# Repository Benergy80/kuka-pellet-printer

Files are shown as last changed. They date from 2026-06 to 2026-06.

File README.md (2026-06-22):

# KUKA Pellet 3D Printer — Conversion Plan

Planning materials for converting a KUKA KR 150 / 180 robot (KR C2 controller)
into a large-format pellet (granule) 3D printer.

## Contents

- **`index.html`** — Interactive implementation plan. Open in any web browser.
  Covers system architecture, the build platform (rigid table, heated bed,
  enclosure/safety), electrical & DeviceNet I/O wiring, the software pipeline,
  calibration, a commissioning roadmap, and an interactive, filterable Bill of
  Materials with live cost totals and charts.
- **`KUKA_Pellet_3D_Printer_Implementation.pptx`** — The same plan as a
  presentation deck with diagrams and charts.
- **`build.js`** — Node.js script (PptxGenJS) that generates the deck.

## Regenerating the deck

```bash
npm install pptxgenjs react-icons react react-dom sharp
node build.js
```

## ⚠️ Safety

This is planning material only. The 480 V three-phase power connection and the
robot safety-circuit wiring (fence interlocks, E-stops) **must** be performed
and validated by a licensed electrician and a qualified machine-safety
integrator. Do not run the robot unattended until safety, thermal, and e-stop
behavior are all proven.

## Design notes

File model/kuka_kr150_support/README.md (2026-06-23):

# KUKA KR 150 robot model (`kr150_2`)

Vendored from **ROS-Industrial** [`kuka_experimental`](https://github.com/ros-industrial/kuka_experimental) → `kuka_kr150_support` (branch `melodic-devel`).

- **License:** Apache-2.0 (ROS-Industrial). Original copyright retained.
- **Contents:** URDF/xacro + meshes — `visual/*.dae` (textured/colored) and `collision/*.stl` (decimated) for the **`kr150_2`** arm, the older 2-series arm that is the closest match to a **KR C2-era** machine.

## Where it's used
- **`/twin.html`** — interactive browser 3D twin. Uses the **collision STLs** (small, fast, no Collada up-axis quirks) assembled with the kinematics below.
- **RViz / MoveIt / Gazebo** — drop the package into a catkin/colcon workspace and use the xacro directly.
- **RoboDK / CAD** — import the **visual DAE** meshes for a higher-fidelity render.

## Kinematic chain (from the package URDF — units: m, °)

| Joint | Origin (xyz) | Axis | Limits |
|---|---|---|---|
| A1 | 0, 0, 0.75 | (0, 0, −1) | −185 … 185 |
| A2 | 0.35, 0, 0 | (0, 1, 0)  | −146 … 0 |
| A3 | 1.25, 0, 0 | (0, 1, 0)  | −119 … 155 |
| A4 | 0, 0, −0.055  | (−1, 0, 0) | −350 … 350 |
| A5 | 1.1, 0, 0 | (0, 1, 0)  | −125 … 125 |
| A6 | 0.23, 0, 0 | (−1, 0, 0) | −350 … 350 |
| flange → tool0 | fixed | rpy (0, 90°, 0) | — |

Note: the `kr150_2` arm geometry approximates the KR C2-era robot. For a different reach/payload variant (e.g. KR 150 L, KR 210), confirm against the robot's rating plate and swap the matching ROS-Industrial support package.

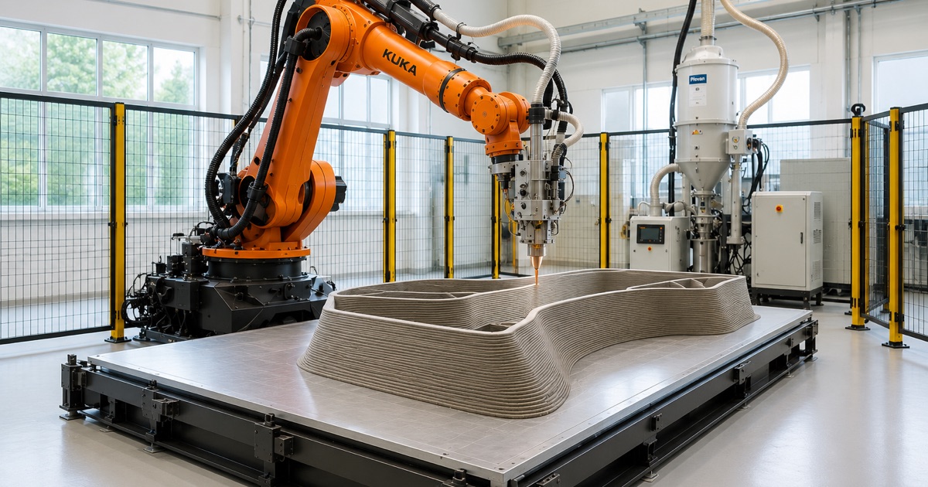
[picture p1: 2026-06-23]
images/og-cover.jpg

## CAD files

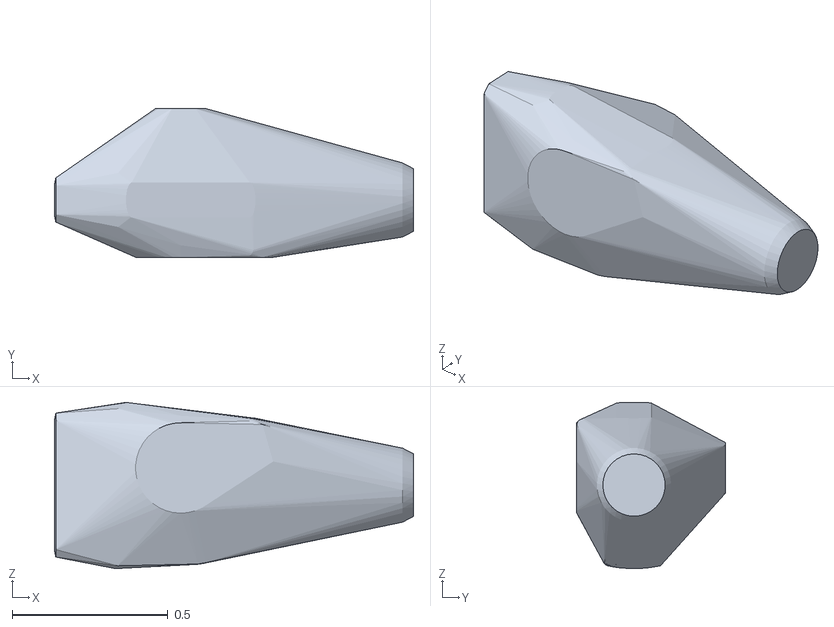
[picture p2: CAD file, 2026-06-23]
model/kuka_kr150_support/meshes/kr150_2/collision/link_3.stl
1.15 x 0.477 x 0.533

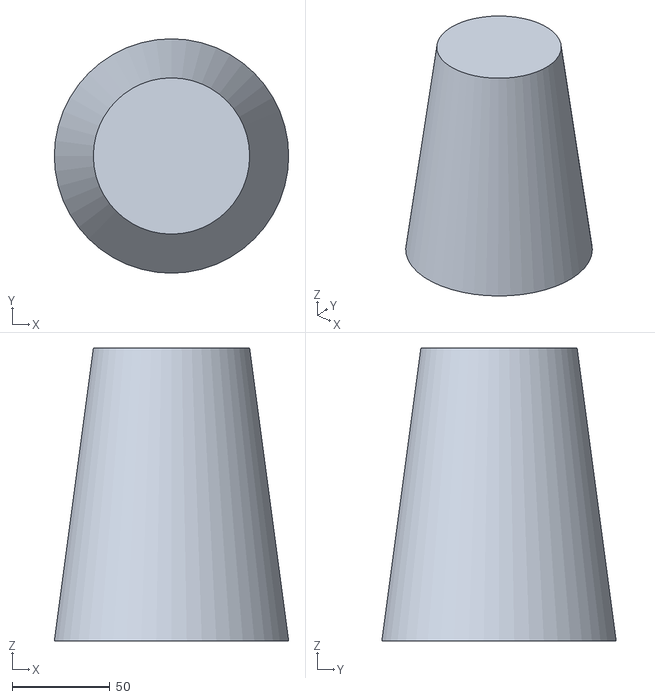
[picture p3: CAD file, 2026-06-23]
samples/vase.stl
120.0 x 120.0 x 150.0

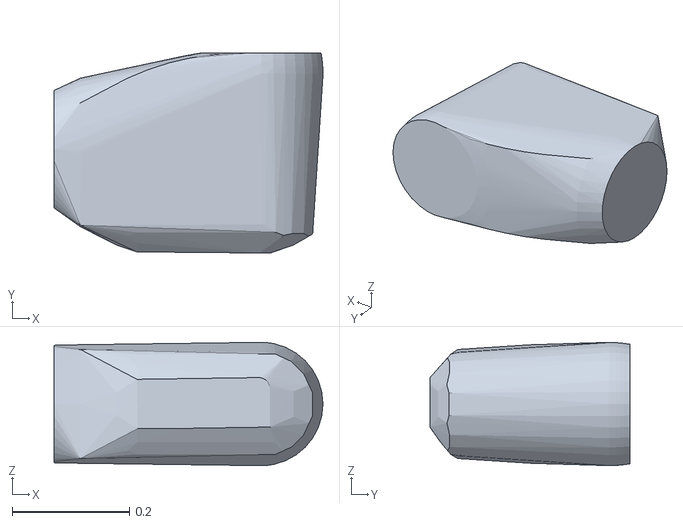
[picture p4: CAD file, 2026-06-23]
model/kuka_kr150_support/meshes/kr150_2/collision/link_4.stl
0.458 x 0.341 x 0.21

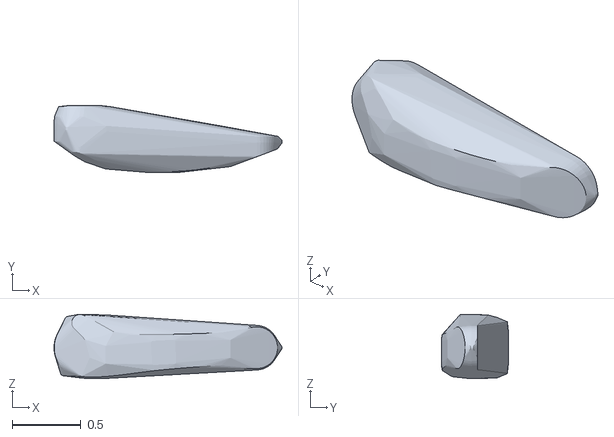
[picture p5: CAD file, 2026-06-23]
model/kuka_kr150_support/meshes/kr150_2/collision/link_2.stl
1.66 x 0.492 x 0.47

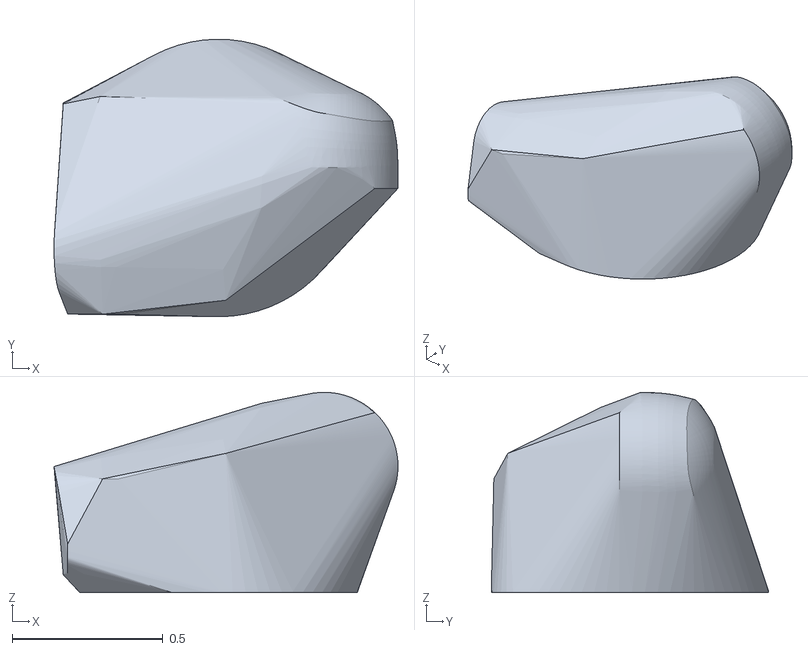
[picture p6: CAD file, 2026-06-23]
model/kuka_kr150_support/meshes/kr150_2/collision/link_1.stl
1.14 x 0.92 x 0.664

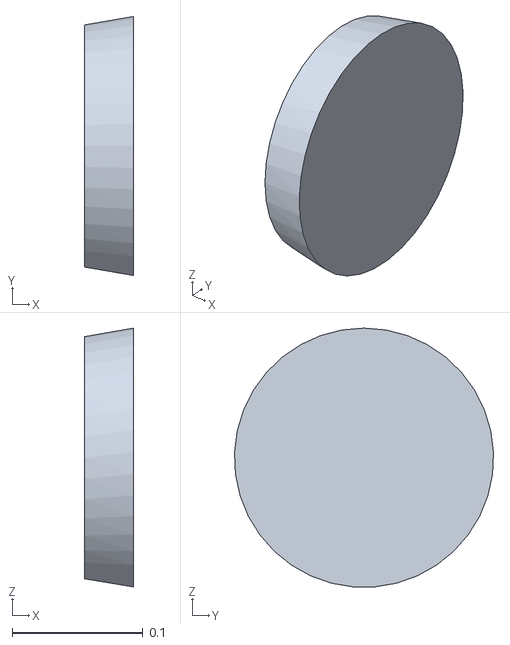
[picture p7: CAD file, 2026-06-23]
model/kuka_kr150_support/meshes/kr150_2/collision/link_6.stl
0.0375 x 0.198 x 0.198

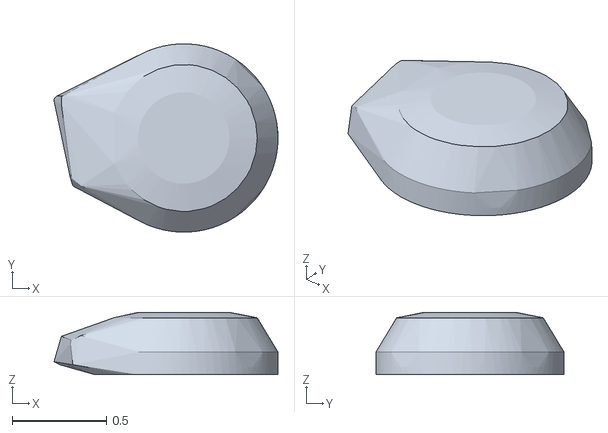
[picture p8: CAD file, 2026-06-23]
model/kuka_kr150_support/meshes/kr150_2/collision/base_link.stl
1.19 x 1 x 0.331

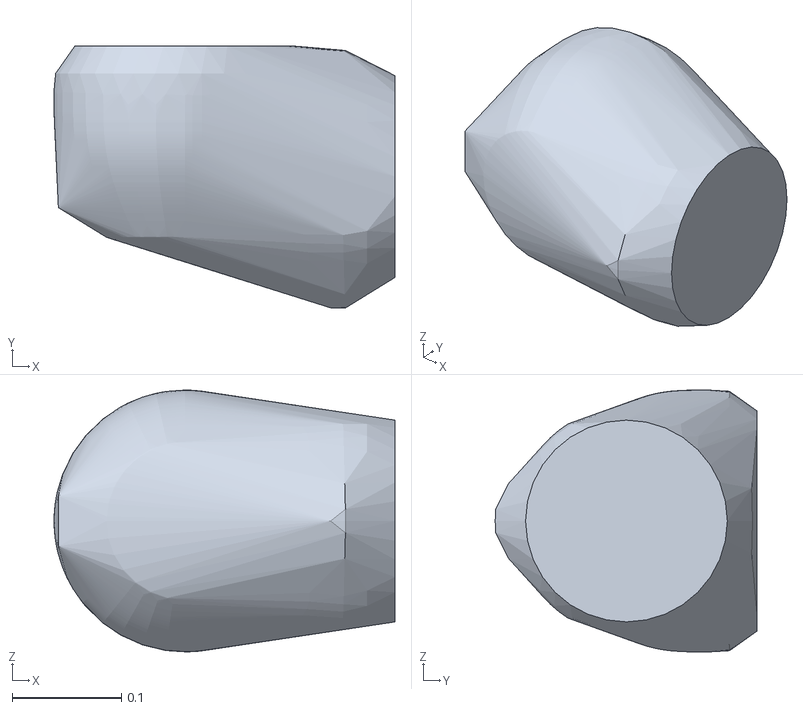
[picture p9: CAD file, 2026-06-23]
model/kuka_kr150_support/meshes/kr150_2/collision/link_5.stl
0.313 x 0.24 x 0.24

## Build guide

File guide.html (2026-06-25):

KUKA Pellet PrinterLFAM Build Manual 3D Twin Overview Download PDF

Engineering Build Manual · LFAM

# Converting a KUKA KR 150/180 into a Pellet 3D Printer

A high-fidelity, primary-source-cited manual — mechanical, electrical & DeviceNet I/O, safety, software & simulation, calibration, and commissioning for a large-format additive manufacturing cell.

KR 150 / 180 · ZH 150/180 I KR C2 · KSS 5.x · KRL DeviceNet I/O Pellet Extrusion (FGF)

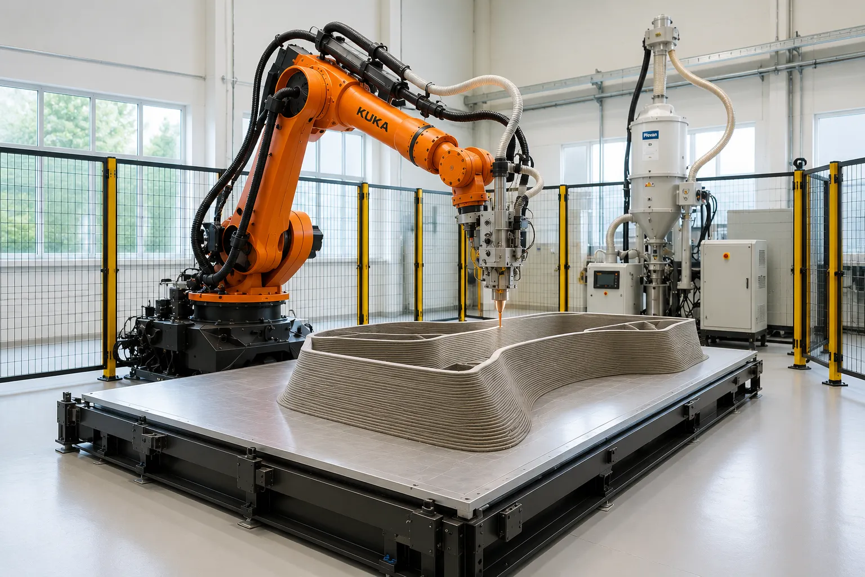
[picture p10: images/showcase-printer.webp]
KUKA robot arm printing a large part from plastic pellets


Revision 1.0 · June 2026 · For planning use — power and safety-circuit work must be performed by qualified, licensed professionals.

Read first — scope & safetyThis is a planning and engineering reference, not a substitute for professional judgment. A KUKA KR 150/180 is a ~1,250 kg machine that moves a multi-kilogram tool at up to ~2 m/s and carries a 350 °C hot end. The 480/400 V power feed and the safety circuit must be executed and validated by a licensed electrician and a qualified machine-safety integrator. Every numbered pin, jumper, and rating below must be confirmed against your specific cabinet's wiring diagram and rating plate before you wire anything. Where a value could not be confirmed against a primary source, it is flagged.

## 01System & specifications

A 6-axis KUKA arm carries a pellet (granule) extruder and prints large parts directly from thermoplastic pellets — no filament. The motion system and the feedstock chain are in hand; the work is integration, a build platform, control I/O, software, and safety.

150–180 kg

Rated payload — carries any pellet head with margin

3100 mm

Max reach (base 1100 mm arm) — defines the build envelope

±0.15 mm

Pose repeatability (ISO 9283), KR 150/180

~1245–1267 kg

Robot mass — drives the foundation design

### Verified robot data (KR 150 / 180 / 210 family)

The KR 150, 180 and 210 share one mechanical platform (1100 mm base arm); they differ mainly in payload and axis speed. "ZH 150/180 I" denotes the KUKA Zentralhand (in-line wrist) rated 150/180 kg — confirming the donor wrist module. Source: KUKA (V)KR 150,180,210 Technical Data.

Parameter | KR 150 | KR 180 | KR 210
Rated payload | 150 kg | 180 kg | 210 kg
Suppl. load (arm / link arm / column) | 50 / 100 / 300 kg | | 50 / 100 / 300 kg
Max reach (base arm) | 3100 mm | | 3100 mm
Repeatability (ISO 9283) | ±0.15 mm | ±0.15 mm | ±0.2 mm
Robot mass | 1245 kg | 1267 kg | 1267 kg
Installed motor capacity | 21.6 kW | 22.8 kW | 23.4 kW
Protection / mounting | IP 65 (wrist); floor or ceiling, ≤5° incline; +10…+55 °C ambient

#### Axis motion ranges (software-limited)

Axis | Range | Speed @ KR 150 | Speed @ KR 180
A1 | ±185° | 110 °/s | 95 °/s
A2 | +90° … −61° | 110 °/s | 95 °/s
A3 | +65° … −209° | 100 °/s | 90 °/s
A4 | ±350° | 170 °/s | 162 °/s
A5 | ±125° | 170 °/s | 164 °/s
A6 | ±350° | 238 °/s | 229 °/s

Verify on the nameplateIf the donor is actually a KR 210 or an "L" long-arm variant, payload and reach change (L-arms reach 3300–3500 mm at reduced payload). Read the model and machine-data number off the robot's rating plate and cross-check in KUKA Xpert.

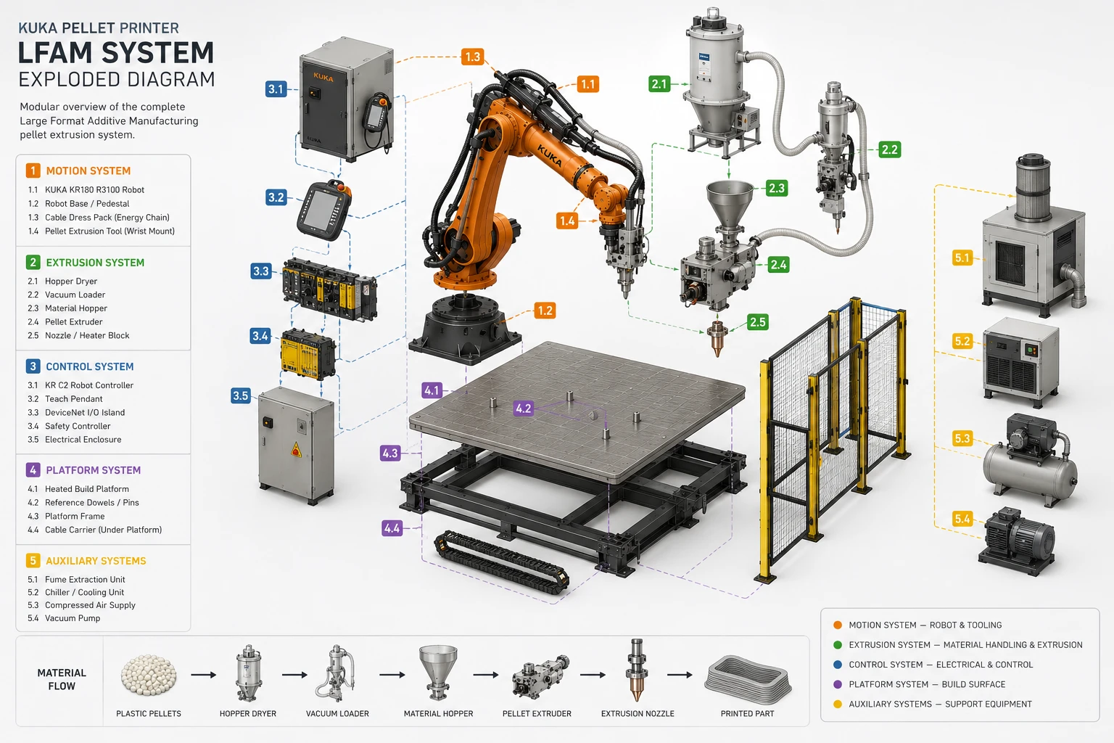
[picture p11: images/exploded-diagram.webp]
Exploded diagram of the LFAM system grouped into motion, extrusion, control, platform, and auxiliary subsystems


System map. Five subsystems — motion, extrusion, control, platform, auxiliary — and how they connect.

## 02Mechanical & tool flange

Only the extruder head rides on the arm; the control box stays off-arm to keep the moving mass and inertia low. The head bolts to the wrist flange through a machined adapter.

### Mounting flange — DIN/ISO 9409-1-A160

The in-line wrist flange is DIN/ISO 9409-1-A160 (Type A, 160 mm bolt-circle). Tooling fastens with M10, grade 10.9 screws; thread engagement 12–14 mm; a locating bushing/dowel fixes orientation. Design the adapter plate to register on the center pilot and one dowel, and follow KUKA's rule that screw grip length ≥ 1.5 × nominal diameter (≥ 15 mm for M10).

Flange feature | Value
Standard | DIN/ISO 9409-1-A160 (160 mm BCD)
Fastening screws | M10 × grade 10.9
Thread engagement | min 12 mm / max 14 mm
Locating | center pilot register + locating bushing (dowel)

Confirm before machiningThe exact bolt count and locating-pin coordinates are dimensioned in KUKA Fig. 16 / the STEP model — pull the CAD from KUKA Xpert (or the ROS-Industrial mesh, §10) and dimension the adapter from it rather than assuming.

### Payload, centre of gravity & inertia

The pellet head (~6 kg) plus adapter, hose drag and any on-arm feed tube must stay within the wrist's load model. Nominal design point: load CG at Lz ≈ 240 mm from the flange face, Lxy ≈ 270 mm from the A6 axis; permissible mass moment of inertia ≤ 75 kg·m² (KR 150). Compute the real values in KUKA.Load and enter them in the controller — an out-of-spec CG/inertia degrades path accuracy and can trip drive faults.

#### Model the head + adapter

- Get mass, CG and inertia of the extruder head, adapter plate, mounted hose section and any cable carrier. Keep the control box and reservoir off the arm.

#### Machine the adapter to A160

- 160 mm BCD, center pilot, dowel bore; material thick enough to be stiff under bead-reaction and decel loads. Route the melt/feed lines so they don't snag through the A4–A6 range.

#### Enter load data

- Run KUKA.Load; enter mass/CG/inertia as the active TOOL load. Verify the arm accepts full-speed moves across the print envelope without overload warnings.

## 03Foundation & build table

The robot base and the print table must not move relative to each other — they share one rigid datum, ideally one concrete slab. If the table shifts, the calibrated BASE frame is lost and Z accuracy goes with it.

### Foundation

Requirement | Value (representative KUKA spec)
Concrete thickness | ≥ 200 mm (heavier cells ~400 mm)
Concrete grade | C20/25 (EN 206-1)
Anchors | chemical (resin-bonded) anchors, Dynamic Set
Base loads (design) | Fv 24 kN · Fh 18 kN · Mk 49 kN·m · Mr 38 kN·m

VerifyUse the KR 150/180 model's own KUKA assembly-instruction foundation drawing for footprint, bolt circle and dynamic forces before pouring.

### Build table

Build a stiff steel weldment with a thick flat top plate. Use cast aluminium tooling plate (MIC-6 or ATP-5/Alca-5) for the build surface — it is internally stress-relieved and holds flatness, where rolled 6061 will not.

Plate | Flatness (as supplied) | At thickness
MIC-6 (Arconic) | 0.005" (0.13 mm) | ≥ 19 mm (¾")
ATP-5 / Alca-5 | 0.005" (0.13 mm) | ≥ 16 mm (⅝")

- Top plate ≥ 15–25 mm on a welded steel sub-frame; flycut/grind after mounting and verify with a straightedge.
- Anchor to the same slab as the robot; level on adjustable feet.
- Machine 2 dowel bores + a datum edge so the BASE frame can be re-taught identically after a bed/plate swap.
- Mount the heated bed on a thermal break so the frame doesn't sink the heat.

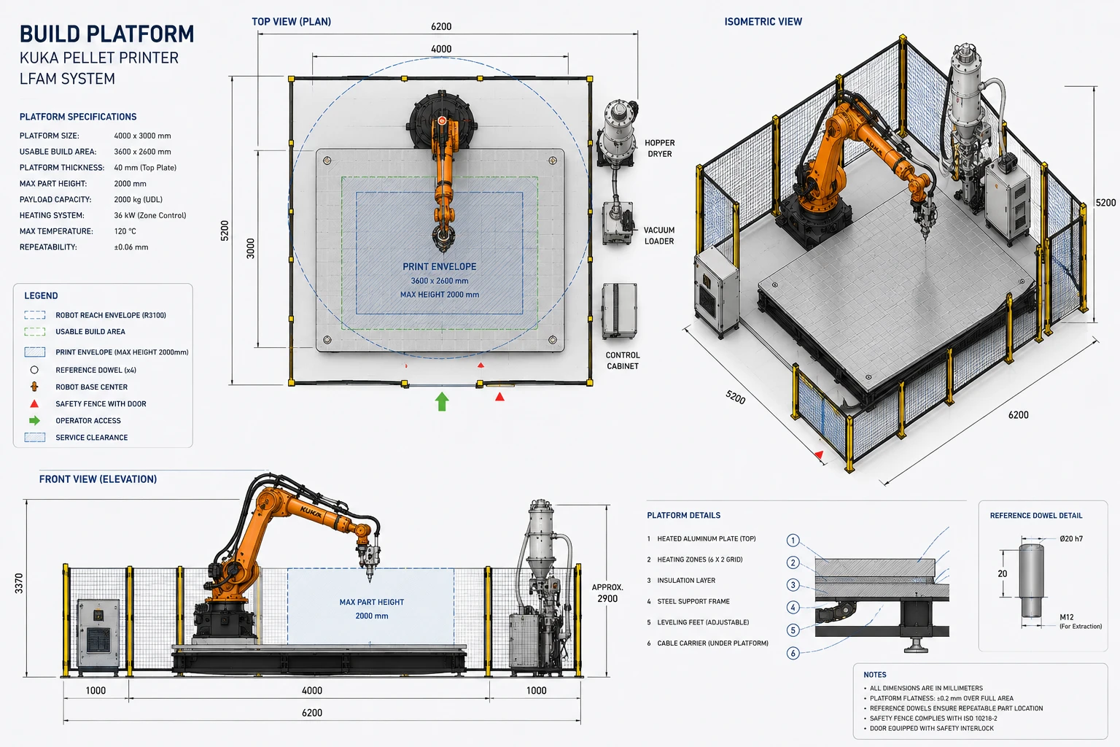
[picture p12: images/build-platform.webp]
Build platform engineering drawing: plan, isometric and front elevation with print envelope, fencing and reference-dowel detail


Build platform — general arrangement. Print envelope inside the reach circle, reference dowels, fencing, and heated-plate stack-up.

## 04Heated bed & thermal

Big beads shrink as they cool and try to peel off the plate. A heated bed plus a warm chamber keep the temperature gradient low — controlling warp and building interlayer bond strength.

### Heater sizing & control loop

Spec a silicone heater at a conservative 2.5–5 W/in² and oversize the area (lower element temperature = longer life). Large LFAM beds land in the 1.5–5 kW+ band; use 240 V to keep current sane. Heat one zone as an independent loop the robot never touches:

// independent bed loop — not on the robot Type-K thermocouple → PID controller → SSR (25–40 A, heatsinked) → 240 V silicone heater

Estimate power from Q = m·c·ΔT (cAl ≈ 900 J/kg·K) and add ~25% margin. Worked example: a 600×600×10 mm aluminium plate (~9.7 kg) from 20→110 °C in 15 min needs ≈ 875 W for the metal alone, ≈ 1.5–2 kW with losses and margin.

Mandatory for multi-kW AC heatAdd an independent thermal cutoff/fuse in series with the heater and a redundant mechanical contactor or hardware over-temp kill, plus GFCI/fusing and a PID runaway alarm. Use vulcanized/clamped (not PSA) heater mounting for >149 °C beds.

### Surface, adhesion & insulation

- Stack: cast aluminium tooling plate → silicone heater bonded underneath → optional PEI sheet or borosilicate as the print surface.
- Adhesion: wide brim (PP needs 10–20 mm) or raft for big beads; temperature-activated adhesives (Magigoo, incl. Magigoo PP; Dimafix for high-Tg ABS/PC/PA). PP adheres only to PP — use PP tape/sheet.
- Insulate: 20–40 mm ceramic-fibre board/blanket under the heater — under-insulation is the #1 reason a bed needs more wattage than calculated (a 5 mm layer tested only 44% efficient).

See §13 for per-polymer bed and chamber temperatures.

## 05Enclosure, fume extraction & safety

This is a non-collaborative industrial robot. The full guarding regime of ISO 10218-2 applies — do not rely on power-and-force limiting. As the integrator, ISO 10218-2 is your governing standard.

### Cell guarding (ISO 10218-2:2025 / ANSI A3 R15.06-2025)

- Fence: guard by height + distance (ISO 13857). Practice: ≥ 2000 mm tall; guards below 1400 mm shall not be used without added measures. Slots ≤ 65 mm; openings >180 mm need additional guarding.
- Gate: safety-rated interlock (ISO 14119) with guard locking; entry forces a stop; restart requires a deliberate action from outside the cell.
- Presence sensing (ISO 13855): S = K·T + C, K = 2000 mm/s, C = 850 mm whole-body. Large arms are usually hard-fenced, with light curtains reserved for a load aperture. Measure your robot+tool stopping distance to size it.
- E-stop (ISO 13850): use Stop Category 1 (controlled decel, then power off) for a heavy arm carrying a hot end.
- Functional safety: design safety functions to PL d, Category 3 (≈ SIL 2) — dual-channel with monitoring.

### Hot-surface, pinch & crush

A 350 °C nozzle is ~5–7× any burn threshold. Per ISO 13732-1 (bare metal), a 1-second touch burns at ~67–73 °C; 1 minute at 51 °C. Keep touchable surfaces near the hot end below ~65 °C or guard/insulate them, and add a hot-surface warning. The arm's mass-in-motion makes impact/crush the dominant severe hazard — size the safeguarded space to max reach + tool envelope + stopping distance.

### Fume extraction

FDM/FGF emits ultrafine particles and VOCs (ABS → styrene; nylon → caprolactam). Enclose the cell and extract at source:

Parameter | Target
Filtration train | HEPA H13/H14 then activated carbon (HEPA alone does not capture styrene/caprolactam vapour)
Best practice | enclose & exhaust outdoors (NIOSH)
Capture velocity | 50–100 ft/min (0.25–0.51 m/s) at the nozzle
Duct transport velocity | ≥ 3500 ft/min (≥ 17.8 m/s) for particulate

Data notePublished emission rates are for desktop FDM; LFAM runs kg/h and hotter, so treat them as a floor and size conservatively.

## 06Electrical & power

The KR C2 connected load is its nameplate rating — not the sum of axis-drive ratings. Size the feeder to the plate.

Parameter | Value (KR C2 ed2005)
Supply voltage | AC 3×400 … 3×415 V (−10% / +10%), 49–61 Hz
Rated connected load — standard | 7.3 kVA (rating plate)
Rated connected load — heavy-duty | 13.5 kVA (palletizing/press duty)
Mains fusing | 3×25 A min … 3×32 A max, slow-blow
RCCB trip (if used) | 300 mA, universal-current sensitive
Controller protection / max axes | IP 54 / 8 axes (6 robot + 2 external)

- A licensed electrician runs the 3-phase feeder, disconnect and grounding, sized to the cabinet rating plate (confirm 7.3 vs 13.5 kVA on your plate).
- The heated bed/chamber, extruder control box, dryer and autoloader each go on their own circuits — these are large independent loads, not part of the robot's 7.3 kVA.

North-American noteMany KR C2 cabinets are 3×400–415 V machines. A 480 V shop feed typically needs a transformer to the cabinet's rated voltage — verify the cabinet's actual input rating before energizing.

## 07Control I/O & DeviceNet

The KR C2 is a native DeviceNet master via its MFC3 card. Add a small remote-I/O island — that island is the entire extruder-integration core. The robot does only three things to the extruder: RUN/STOP, set speed, read fault.

### DeviceNet I/O island

Correction — common mistakeThe BK5120 is a CANopen coupler, not DeviceNet. For DeviceNet use the BK5200 (standard) or BK5250 (compact) Beckhoff coupler. Set MAC ID (0–63) and baud (125/250/500 kbaud) on the coupler switches to match the master, and fit 121 Ω terminators at both physical ends of the trunk — a missing terminator is the #1 cause of intermittent DeviceNet faults.

Position | Terminal | Function
Coupler | BK5200 / BK5250 | DeviceNet bus coupler (e.g. MAC ID 5, 500 kbaud)
Slot 1 | KL1xxx (e.g. KL1408 DI) | Extruder fault / ready inputs (24 V)
Slot 2 | KL2xxx (e.g. KL2404 DO) | Extruder RUN/STOP, heater enable (24 V)
Slot 3 | KL4004 (4-ch AO 0–10 V) | Extruder speed setpoint
End | KL9010 | Bus end terminal (required)

### Analog scaling — get this right

Correction — analog full scaleThe Beckhoff KL4004 uses 15-bit two's-complement: 10 V = 0x7FFF = 32767, 5 V = 0x3FFF = 16383, 0 V = 0. The often-quoted 0x6C00 / 27648 is the Siemens convention and will only reach ≈ 8.44 V at "full" command on a Beckhoff terminal. In KRL, $ANOUT[1] is a REAL from −1.0 … +1.0 (fraction of full scale): $ANOUT[1]=1.0 → 10 V, 0.5 → 5 V. To command a voltage: $ANOUT[1] = volts / 10.0.

### iosys.ini & system-variable mapping

Set the master node/baud in devnet.ini (index must start at [1]), then map physical bytes to KRL variables in iosys.ini. Analog channels occupy the start of the I/O image, which pushes the digital output byte back — so the digital offset is not 0:

; devnet.ini — master node + baud [1] macid=5 baudrate=500 ; iosys.ini — map bytes to KRL system variables [DEVNET] INB0=5,0,x1 ; $IN[1..8] ← extruder fault/ready OUTB0=5,4,x1 ; $OUT[1..8] → RUN/STOP, heater enable (offset 4: after analog) anout1=5,0,16,3,CAL32768 ; $ANOUT[1] → speed, KL4004 ch.1

KRL variable | Physical | Use
$IN[1..8] | KL1xxx via INB0 | 1 = fault, 2 = ready (your assignment)
$OUT[1..8] | KL2xxx via OUTB0 | $OUT[1]=TRUE → extruder RUN
$ANOUT[1] | KL4004 ch.1 via anout1 | speed setpoint, REAL −1.0…+1.0

VerifyByte offsets depend on your exact terminal count/order — derive them from the coupler's process image, don't copy literally. Confirm the actual output word with a meter at $ANOUT[1]=1.0 (expect ≈ 9.997 V).

### X11 safety circuit (ESC)

The KR C2 safety system is the ESC — a dual-channel, computer-monitored closed ring. External safety devices enter through connector X11 and are wired as a test-output → contact → input loopback, per channel (A and B). This is why a single jumper is never acceptable.

ESC signal | Meaning | Channels
ENA | External EMERGENCY STOP | A / B
NA / LNA | Local E-stop (KCP button) | A / B
BS | Operator Safety (safety gates) | A / B
QE | Qualifying input (range limit / load station) | A / B
ZS1 / ZS2 | Enabling switch / panic | A / B
BA | Operating mode (Test / Auto) | A / B
TA(A) / TA(B) | Test-pulse outputs (24 V) | A / B

; dual-channel external E-stop (loopback pattern) TA24V(A) ── [cell E-stop contact 1] ── ENA(A) TA24V(B) ── [cell E-stop contact 2] ── ENA(B) ; Operator Safety (gate) follows the same pattern on BS(A)/BS(B)

Factory jumpers & pin numbersThe KR C2 ships with an X11 jumper plug that short-circuits the external safety circuit for bench power-up. It must be removed and replaced with real, dual-channel, Category-3 safety devices (cell E-stop into ENA, gate interlock into BS) for any operational cell. The numbered X11 pins vary by ESC board variant (CI3 Standard/Extended/Bus/Tech) — obtain your cabinet's own X11 wiring diagram and verify every pin before wiring. A robot E-stop does not de-energize the extruder heater unless you wire it to do so.

## 08Extruder integration

For a servo-driven pellet head (the class of MDPE10 / CEAD), the control interface is the servo drive's I/O — which maps cleanly onto the three robot signals above.

Robot signal | Extruder interface | KRL
RUN / STOP | servo enable digital input | $OUT[n]
Set speed | 0–10 V analog velocity command | $ANOUT[1]
Fault / ready | drive alarm/ready digital output | $IN[n]

Know your headServo heads (MDPE10, CEAD E25/E50) take digital enable + 0–10 V speed + digital fault — exactly this design. Stepper heads (Dyze Pulsar, Mahor) use STEP/DIR pulse trains and need an intermediary motion board (Duet/Klipper) between the controller and the head. Confirm your head's interface and signal levels (logic vs 24 V), and add interposing relays / isolation as needed. Resolve this before ordering the I/O island.

### Process rules that differ from filament FDM

- No retraction. The screw turns one way only — plan continuous-deposition toolpaths; add a mechanical anti-ooze/needle valve if seam ooze is a problem.
- Heaters off when idle. A barrel held hot degrades its melt charge (can require a screw replacement). Purge 250–500 g before a stop or material change.
- Active vacuum feeding. A vacuum loader conveys dried pellets to the head hopper; route the hose on swivel points so it follows the arm.
- 3–4 PID heat zones (feed / transition / metering + nozzle), Type-K thermocouples — each self-regulating, never on the robot.

### Bead geometry & throughput

Pellet heads are screw-flow-limited, not nozzle-limited — a bigger nozzle lays the screw's fixed output as a wider/slower bead. Rules: bead width ≈ 1.1–1.5 × nozzle; layer height ≈ 0.4–0.5 × bead width (going higher risks weak interlayer bonds). For a ~4 kg/h head, pair a 2.5–3 mm nozzle and run ~40–100 mm/s at constant speed for constant flow.

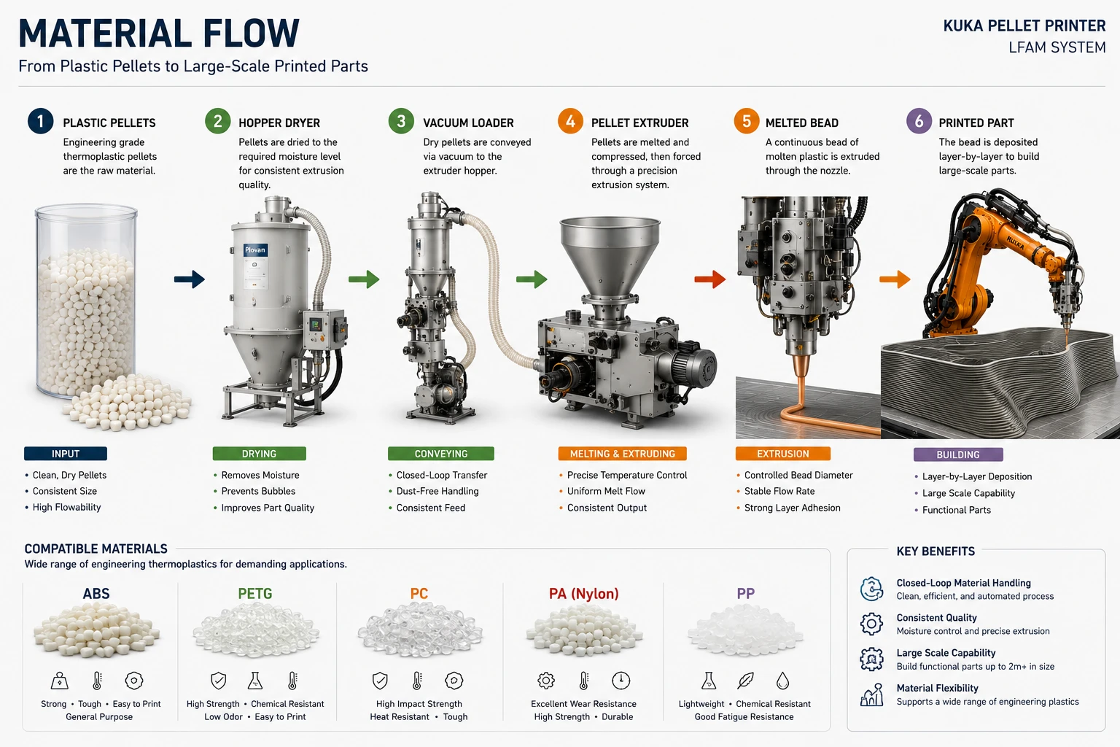
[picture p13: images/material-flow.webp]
Material flow: pellets, hopper dryer, vacuum loader, pellet extruder, melted bead, printed part


Material flow. Dried pellets → vacuum loader → extruder → controlled bead → part.

## 09Software & simulation

Four ways to get from CAD/STL to robot motion. For a KR C2 (KSS 5.x), the pragmatic path is offline KRL — generate, simulate, then transfer; do not stream for production printing.

Path | Model | Fidelity / control | Multi-axis | Cost | KR C2 fit
CuraToKRC2 | Static KRL playback (.src, $ANOUT[1]) | Low — planar, fixed wrist, naive chunking | No (3-axis) | Free (GPL) | Purpose-built; analog flow + C_DIS blending; RAM-chunked
KUKA|prc | Parametric KRL (.src+.dat) | High — full sim, collision/singularity/reach | Yes (true 6-axis + ext. axes) | Free community / €450 academic | KR C2 supported; proven LFAM precedent
RoboDK | Offline post (KRC2 post) | High — KRC2 post has 3D-print mods built-in | Good | $3,995 Pro | KRC2 / KRC2_DAT posts; kukabridge offline transfer
ROS RSI (kuka_experimental) | Streamed joint correction (UDP, 12 ms) | Real-time but research-grade, brittle | Yes (you own kinematics) | Free (OSS) | Confirmed KR C2 + KSS 5.x via RSI 2.2/2.3

Recommended pathStart: CuraToKRC2 — free, purpose-built for KR C2, to commission the extruder $ANOUT[1] mapping and DeviceNet I/O on flat test prints. Production: RoboDK Professional with the stock KUKA KRC2 post (which already includes 3D-printing modifications), KRC2_DAT for large toolpaths, analog flow via PRINT_E_AO → $ANOUT[n], on/off via M64/M65 → $OUT[n]. If you need non-planar / multi-axis: KUKA|prc. Avoid for production: any real-time streaming (ROS RSI / RoboDK online).

### CuraToKRC2 — what it does

An open-source Cura output plugin that exports .src KRL. It writes a printMain.src orchestrator that calls chunked printN.src subprograms (default ~25,000 lines/chunk for KR C2 RAM). A krl_config.json sets tool A/B/C orientation, HOME, Tool/Base numbers, and the flow constant; flow is mapped to $ANOUT[1] with a TRIGGER WHEN DISTANCE at the start of each print move:

$ANOUT[1] = 0.0123 WAIT SEC 0.200 TRIGGER WHEN DISTANCE=0 DELAY=0 DO $ANOUT[1]=0.0150 $VEL.CP = 0.01667 LIN {X 100.0,Y 50.0,Z 0.2,A -178.6,B 0.0,C -180.0} C_DIS ; print move $ANOUT[1] = 0.0 ; travel: flow off

LimitsPlanar / 3-axis only (fixed wrist), static acceleration, and raw line-count chunking can split a state-setting line from its move at a boundary — validate chunk seams. Relative Extrusion (M83) is mandatory in the Cura profile or it over-extrudes badly. The plugin is new (mid-2026, single author).

### Cura settings for LFAM pellet

Setting | Desktop FFF | LFAM pellet
Nozzle size / line width | 0.4 / ~0.48 mm | nozzle as fitted / ≈ 1.1–1.25 × nozzle
Layer height | 0.2 mm | ≈ 0.4–0.5 × bead width
Print speed | 50–60 mm/s | ~15–100 mm/s, held constant (steady flow)
Retraction | on | off — use coasting / wipe ≥ line width
Relative extrusion | off | on (M83)
Walls | 2–4 | 1 (single bead) or 2; spiralize for hollow
Cooling fan | on | off / very low — manage layer time for weld strength

### ROS RSI — fine-grained reality

The kuka_rsi_hw_interface in ros-industrial/kuka_experimental (https://github.com/ros-industrial/kuka_experimental) streams RSI XML over UDP. The KR C2 sends a <Rob> packet every IPO cycle with an IPOC counter; the ROS PC must reply with axis corrections carrying the matching IPOC within ~10 ms or the controller faults. The repo's krl/KR_C2/ros_rsi.src uses the older ST_* RSI-2.x API (distinct from the KR C4 .rsi object diagram) — confirmed working on KSS 5.x with RSI 2.2/2.3; UDP port 49152; per-axis corrections AK.A1…AK.A6.

VerdictRSI is a real-time joint-correction interface, not a print engine — you would build the entire Cartesian-toolpath → joint-trajectory → extruder-sync stack yourself, on an RT-Preempt kernel, with nothing gained over offline KRL for continuous bead deposition. Excellent for research; wrong tool for first production.

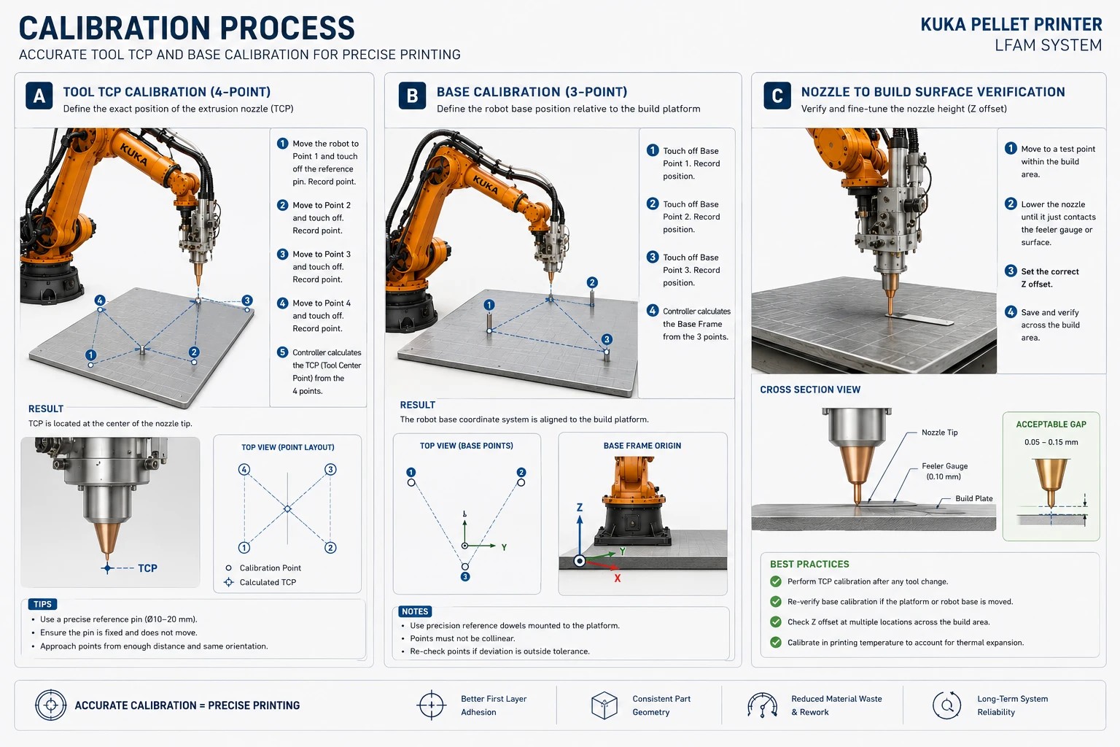
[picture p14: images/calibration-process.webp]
Calibration process: Tool TCP 4-point, Base 3-point, and nozzle-to-surface Z-offset verification


Calibration overview (detailed in §11): TCP, Base, and Z-offset verification.

## 103D models & the digital twin

Build a digital twin to verify reach and collisions in the print envelope, author/verify toolpaths offline, and validate the BASE/TOOL frames before touching the real arm.

### Where to get the 3D model

Source | KR models | Formats
KUKA Download Center / Xpert (login) | KR 150 R3100-2 etc. | STEP/IGES (behind my.KUKA login)
ROS-Industrial kuka_kr150_support | kr150_2 (KR C2-era arm), kr150r3100_2 | .dae visual + .stl collision, URDF/xacro — open, no login
RoboDK robot library | KR 150 R3100-2 + variants | .robot (sim-ready)
TraceParts / GrabCAD | KR 150/180/210 family | STEP, IGES, STL, native CAD

The ROS-Industrial meshes are the most accessible (open, inspectable). The repo's kuka_kr150_support ships two arm variants — use kr150_2 for a true KR C2-era machine — with one .dae/.stl per link (base_link, link_1…6, flange, tool0) and an OPW kinematic definition. Mount your extruder mesh at tool0.

### Simulators

Tool | KR C2 realism | Offline KRL | Cost
RoboDK | KRC2 post-processors (since KRC2) | Yes — .SRC/.DAT | Paid (free trial)
ROS · MoveIt / RViz / Gazebo | URDF only — no controller emulation | No (ROS trajectories) | Free / OSS
KUKA.OfficeLite + KUKA.Sim | Highest — runs the real KSS image as a Virtual Robot Controller | Native, bit-accurate | Licensed
Visual Components | Cell-level KUKA sim | Via plugins | Licensed

Recommended twin stackRoboDK (load KR 150 R3100-2, KUKA_KRC2 post) as the working tool, with ROS-Industrial kuka_kr150_support + MoveIt/RViz as a free cross-check of reach and joint-limit collisions. Reserve KUKA.OfficeLite/KUKA.Sim for final validation if the posted KRL must be guaranteed identical to hardware — note a KSS 5.x VRC image may be legacy/hard to license today.

→ Open the interactive 3D twin — a browser model of the KR 150 (built from kuka_kr150_support) where you can jog all six axes and read the live tool-tip position against the print envelope.

Representative joint limits from the ROS-Industrial URDF (radians): A1 ±3.23, A2 −2.44…−0.087, A3 −2.09…+2.93, A4 ±6.11, A5 ±2.18, A6 ±6.11 — consistent with the degree ranges in §1.

## 11Calibration

Tie the model, the nozzle and the table together: a Tool (TCP) frame at the nozzle tip and a Base frame on the table. Calibrate hot.

#### Tool (TCP) — XYZ 4-Point

- Jog the nozzle tip to one fixed reference point from 4 sufficiently different orientations; the controller computes the TCP (accept error < 1.0 mm). Enter the tool A/B/C to match your software config. Save as the Tool number.

#### Base — 3-Point

- With the taught TCP, touch the table's three reference features: origin, a point on +X, a point in the +XY plane. This builds the print coordinate frame. Save as the Base number.

#### Calibrate hot

- Aluminium grows ~23 µm/m·°C — a 1 m plate moves ~2.3 mm over 100 °C. Teach the Base frame at operating temperature, not cold.

#### Nozzle Z-offset

- Lower the nozzle to a feeler gauge / surface; set the Z offset to a 0.05–0.15 mm first-layer gap; verify at multiple points across the build area.

#### Verify

- Jog to Base 0,0,0 — the nozzle should sit at the table origin with +X/+Y along the table edges. Re-touch references after any crash.

## 12Commissioning & first print

Gate everything on safety. Do not run the arm near the table until the door interlock and every E-stop are proven to stop it.

#### Electrical

- Power to all cabinets; verify breakers, grounding, E-stops. Bring up the bed/chamber loops on their own circuits.

#### Safety validated

- Replace the X11 jumpers with real dual-channel devices; prove the gate interlock and every E-stop physically stop the robot. (Qualified integrator.)

#### I/O bench test

- Verify $IN/$OUT/$ANOUT against the DeviceNet island with a meter; confirm $ANOUT[1]=1.0 → ~10 V and RUN/STOP toggling — extruder de-energized.

#### Tool & Base calibration

- TCP 4-point, Base 3-point, Z-offset — hot (§11).

#### Dry run in air

- Run a sliced program at height, extruder off; check reach, collisions, blending and chunk seams against the simulation.

#### Heat soak

- Bring the bed and chamber to setpoint; dry the pellets to spec (§13).

#### First print (PP / PETG)

- A small single-wall part: tune flow constant ($ANOUT → bead width), layer time and adhesion.

#### Scale up

- Larger parts and engineering resins (ABS/PC/PA) once the process is repeatable.

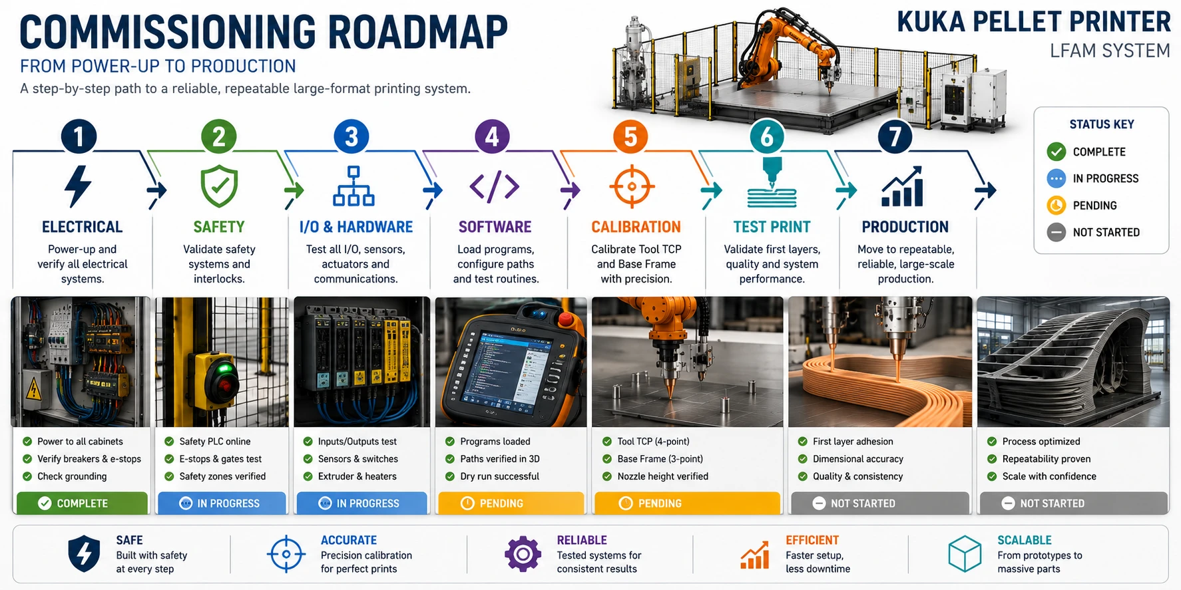
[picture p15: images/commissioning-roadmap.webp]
Commissioning roadmap: electrical, safety, I/O, software, calibration, test print, production


Commissioning roadmap. Seven gates from power-up to production.

## 13Materials reference

Per-polymer windows. Values vary by grade — always defer to the resin TDS; PET/PETG, PC and PA are hydrolysis-sensitive and must be dried in a closed-loop desiccant dryer to −40 °C dew point.

Polymer | Class | Bed °C | Chamber °C | Dry °C / hr | Hydrolysis
PP | semicryst. | 85–100 | warm enclosure | (low uptake) | no
PETG | amorphous-ish | 70–90 | ~60 | 65–70 / 4–6 | yes
ABS | amorphous | 100–110 | ~80–110 | 80–90 / 2–4 | no (cosmetic)
PA (nylon) | semicryst. | 70–90 | enclosure req. | 80 / 4–6 | yes
PC | amorphous | 110–130 | ~80–120 | 120 / 2–4 | yes
PET | semicryst. | 70–90 | ~60 | 150–180 / 4–6* | yes

*PET must be crystallized above Tg (~80 °C) before high-temp drying or it cakes. All hygroscopic resins: −40 °C dew point, dew-point + inlet-temp alarms on the dryer.

## 14Bill of materials

Entry-path budget for the items still to buy. Costs are planning estimates (USD); the gating item is the extruder control interface.

Subsystem | Item | Status | Est. cost
Motion | KUKA KR 150/180 + KR C2 + KCP2 | Have | $0
Extrusion | Pellet extruder (4 kg/h servo) | Have | $0
Material | Hopper dryer + vacuum autoloader | Have | $0
Control | Extruder I/O interface (DeviceNet island) | Buy — gating | ~$300
Extrusion | Flange adapter plate (ISO 9409-1-A160) | Buy | ~$1,000
Platform | Heated build bed (Al + silicone + PID) | Buy | ~$2,500
Platform | Rigid print table (steel weldment) | Buy | ~$1,500
Safety | Fencing / interlocks / E-stops | Buy | ~$4,000
Electrical | Electrician install (feeder + disconnect) | Buy | ~$3,500
Control | Toolpath software (RoboDK Pro, optional) | Optional | ~$3,995

Entry-path hardware (excluding optional software): ≈ $12,800.

## 15Sources

Primary and reputable references used to compile this manual. Pin numbers, ratings and material windows must still be confirmed against your specific equipment.

#### KUKA hardware, controller & safety

- KUKA — (V)KR 150,180,210 Technical Data (payload, reach, axis ranges, flange A160): robot-store.co.uk KR210 manual PDF (https://www.robot-store.co.uk/wp-content/uploads/2021/07/KR210-Robot-Manual.pdf)
- KUKA — KR C2 edition2005 Specification (7.3 kVA, voltage, DeviceNet/MFC3, IP54): kr_c2_ed05_spec.pdf (http://www.wtech.com.tw/public/download/manual/kuka/krc2ed05/kr_c2_ed05_spec.pdf)
- KUKA — KR C2 ed2005 ESC Electronic Safety Circuit (X11, ENA/BS/QE, jumper plug): ESC workbook PDF (http://www.wtech.com.tw/public/download/manual/kuka/krc2ed05/KRC2ed05%20Esc-Safety-Circuit.pdf)
- KUKA — KR C2 DeviceNet: KRC2 DeviceNet PDF (http://www.wtech.com.tw/public/download/manual/kuka/krc2ed05/KRC2%20DeviceNet.pdf)

#### Electrical / DeviceNet

- Beckhoff — KL400x Analog Output (KL4004 wiring; 10 V = 0x7FFF = 32767): kl400xen.pdf (https://download.beckhoff.com/download/document/io/bus-terminals/kl400xen.pdf)
- Beckhoff — BK52x0 DeviceNet Bus Coupler (BK5200/BK5250, MAC ID, terminator): bk52x0en.pdf (https://download.beckhoff.com/download/document/io/bus-terminals/bk52x0en.pdf)
- robot-forum.com — iosys.ini DeviceNet config (anout1 CAL32768, byte offset): thread 25109 (https://www.robot-forum.com/robotforum/thread/25109-devicenet-configuration-in-iosys-ini-help-please/)

#### Extruder, platform, materials & safety

- Massive Dimension MDPE10 (servo, 0–10 V, 4 PID zones): massivedimension.com (https://massivedimension.com/products/mdpe10-massive-dimension-direct-print-particle-extruder)
- Dyze Design Pulsar — flow-to-RPM, no retraction: docs.dyzedesign.com (https://docs.dyzedesign.com/pulsar.html)
- ORNL / Cincinnati BAAM design guidelines (bead/layer ratios): BAAM Design Guidelines (http://wwwassets.e-ci.com/PDF/Products/BAAM-Design-Guidelines.pdf)
- ISO 10218-2:2025 (robot cell integration): iso.org/standard/73934 (https://www.iso.org/standard/73934.html)
- ISO 13732-1 (hot-surface burn thresholds): ISO 13732-1 sample (https://cdn.standards.iteh.ai/samples/43558/98c04ac5d4a849859d8e6e67f7c01782/ISO-13732-1-2006.pdf)
- Novatec — resin drying dew point: novatec.com (https://www.novatec.com/knowledge-center/resin-moisture-drying/resin-drying-basics/understanding-dew-point-in-resin-drying/)

#### Software, models & simulation

- CuraToKRC2 plugin: github.com/nikoladim123/CuraToKRC2 · robot-forum 55449 (https://www.robot-forum.com/robotforum/thread/55449-open-source-cura-to-kuka-krl-src-plugin-for-krc2-3d-printing-additive-manufactur/)
- ROS-Industrial — kuka_experimental (https://github.com/ros-industrial/kuka_experimental) (KR_C2 RSI driver, kuka_kr150_support) · ros-industrial/kuka (https://github.com/ros-industrial/kuka)
- KUKA|prc (Robots in Architecture): robotsinarchitecture.com (https://robotsinarchitecture.com/kuka-prc/)
- RoboDK — robot 3D printing & KRC2 post: robodk.com 3D printing (https://robodk.com/doc/en/Robot-Machining-Robot-3D-Printing-Project.html) · KR 150 R3100-2 (https://robodk.com/robot/KUKA/KR-150-R3100-2)
- KUKA.OfficeLite (virtual KR C): kuka.com OfficeLite (https://www.kuka.com/en-us/products/robotics-systems/software/simulation-planning-optimization/kuka_officelite)

KUKA Pellet Printer — LFAM Build Manual · Rev 1.0 · June 2026

← Back to overview · Download PDF

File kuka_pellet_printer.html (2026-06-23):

×

Industrial Additive Manufacturing

# Converting a KUKA Robot into a Pellet 3D Printer

Implementation plan — platform, wiring & software. An interactive build guide and bill of materials.

KR 150 / 180 KR C2 Controller Pellet Extrusion (LFAM)

JUNE 2026

The Machine

## A KUKA arm, building large

The full cell in operation — the 6-axis arm carrying the pellet head over a heated build platform, with the hopper dryer and feed chain behind a guarded fence.

KUKA robot arm printing a large wavy part from plastic pellets, with hopper dryer and control cabinet behind a yellow safety fence

LFAM cell, printing. Pellet-fed large-format additive manufacturing on a 6-axis KUKA arm. Click to enlarge

The Build Manual

## A 15-section, primary-source-cited engineering manual

Every aspect of the conversion in depth — mechanical & tool flange, electrical & DeviceNet I/O, safety, software & simulation, calibration, commissioning, and a full materials reference. Available as a web manual and a downloadable PDF.

Read the manual → ↓ Download PDF ↻ Open the 3D twin

The Goal

## A robotic large-format pellet printer

A 6-axis KUKA arm carries a pellet extruder and prints large parts directly from plastic granules — no filament. The heavy-payload arm, the extruder, and the full feedstock chain are in hand; the work ahead is integration, a build platform, and safety.

150–180 kg

Robot payload — carries any pellet head with margin

3100 mm

Reach (base arm) — defines the build envelope

3–4 kg/h

Extruder output — moderate LFAM throughput

0–350 °C

Melt range — covers PP, PETG, ABS, PA, PC

What's in Hand

## Current assets

#### Robot + Controller

KUKA KR 150 / 180 KR C2 (MP9), KCP2 pendant 480V 3-phase

Have

#### Pellet Extruder

4 kg/h vertical servo 1200 W · 0–350 °C 1.5–3 mm nozzle

Have

#### Hopper Dryer

INTSUPERMAI 110 lb Dries hygroscopic resins (ABS, PC, PA, PET)

Have

#### Vacuum Autoloader

INTBUYING XC-300G 300 kg/h · 7.5 L Feeds the extruder hopper

Have

Material flow infographic: plastic pellets to hopper dryer, vacuum loader, pellet extruder, melted bead, and printed part — with compatible materials ABS, PETG, PC, PA, and PP

Material flow. From engineering-grade pellets through drying, conveying, melting, and extrusion to a finished large-format part. Click to enlarge

Where You Stand

## The four subsystems

A

#### Motion

Robot arm + KR C2 controller

Have

B

#### Extrusion

Pellet extruder, heat zones, nozzle

Have

C

#### Control

Slicer → robot toolpath + extruder sync

To build

D

#### Platform

Dryer + feed (done); bed, table, enclosure

Partial

System Architecture

## What connects to what

##### CAD Model

STL part to print

→

##### Slicer PC

Cura + CuraToKRC2 → .src / .dat

→

##### KR C2 Controller

Runs KRL motion program

→

##### DeviceNet I/O

BK5200 island

↓

##### Extruder Control Box

$OUT → RUN/STOP · $ANOUT[1] → speed (0–10 V) · $IN ← ready / fault

↓ robot carries the head

##### Robot Arm

follows the toolpath

→

##### Heated Build Bed

part adheres here

##### Dryer

dries pellets

→

##### Autoloader

vacuum-feeds hopper

Self-regulating loops

Barrel heat · bed PID · chamber · dryer — each runs on its own controller, not the robot.

Amber = robot-controlled in sync with motion · Steel = mechanical / feed path

Exploded diagram of the LFAM system grouped into motion, extrusion, control, platform, and auxiliary subsystems

Exploded system view. Every module mapped to its subsystem — motion, extrusion, control, platform, and auxiliary support. Click to enlarge

The Core Idea

## The robot does only three things to the extruder

#### RUN / STOP

Digital output $OUT[n]

Extrude on print moves, stop on travel moves.

#### SET SPEED

Analog output $ANOUT[1]

0–10 V proportional to sliced flow rate.

#### READ FAULT

Digital input $IN[n]

Pause the print on an extruder fault.

#### Everything thermal regulates itself.

Barrel heat zones, the heated bed, the chamber, and the dryer each run on their own controllers. The robot never manages temperature — which keeps the integration small and robust.

Platform — the three things still to build

## Build platform & enclosure

Build platform engineering drawing: top, isometric, and front elevation views with dimensions, specifications, and reference dowel detail

Build platform — general arrangement. Plan, elevation, and isometric views with the print envelope, reach, fencing, and reference-dowel detail. Click to enlarge

1 · Rigid print table, tied to the robot's base frame ▶

1. Size the build area to the reach — keep it ~1.0–1.5 m square, set 0.7–1.5 m in front of the base.
2. Build a stiff steel weldment with a thick flat top plate (≥15–20 mm) — it must not flex when the heavy arm decelerates.
3. Anchor it to the floor, ideally the same slab as the robot, so they can't move relative to each other.
4. Add 3 hard reference features (dowels / machined pockets) at known XY — these become the base-calibration points.
5. Mount the heated bed on top, on a thermal break so the frame doesn't sink the heat.

Why it matters: origin + 2 points teach the print coordinate system, so slice Z=0 equals the real table top. If the table shifts, Z accuracy is lost.

2 · Heated build bed — adhesion & warp control ▶

1. Build surface: flat aluminum tooling plate or borosilicate glass, sized to the build area.
2. Heat with a high-wattage 240V silicone pad bonded underneath (LFAM beds run ~1.5 kW to 5 kW+).
3. Control as an independent loop — thermocouple → PID controller → SSR → heater.
4. Mount on the table over insulation + thermal-break standoffs to protect it and save energy.
5. Adhesion: PEI sheet or glue, plus a wide brim/raft in the slice for big beads.

Control loop: Thermocouple → PID controller → solid-state relay → silicone heater. Runs by itself — the robot never sets bed temperature.

3 · Enclosure, fencing & safety interlocks ▶

1. Machine guarding (required): fence beyond the swept volume, one interlocked door, E-stops inside and out. A KR 150/180 at speed is lethal.
2. Thermal & fume chamber: insulated / poly panels keep a warm chamber (~60 °C, up to 150 °C) and contain fumes — duct an extractor out.
3. Wire the door interlock into Operator Safety (X11 pins C8–C10 / C9–C11, dual channel).
4. Wire external E-stops to X11 pins C14–C15 / C16–D1.
5. Replace the factory bridges with the real safety devices — never leave them jumpered.

Safety-circuit wiring must be done and validated by a qualified machine-safety integrator — not improvised with permanent jumpers.

Electrical & I/O

## The DeviceNet I/O island

The KR C2 talks to the world over DeviceNet. Add a small remote-I/O island; that is the whole integration core.

##### KR C2

DeviceNet master

→

##### BK5200

DeviceNet coupler · MACID 11

→

##### KL4004 — Analog Out

$ANOUT[1] → extruder speed (0–10 V)

##### KL2xxx — Digital Out

$OUT[n] → extruder RUN / heater enable

##### KL1xxx — Digital In

$IN[n] ← extruder ready / fault

#### Mapped in iosys.ini

ANOUT1=11,0,16,3,CAL32768 outb0=11,8,x3 ; full-scale 0x7FFF = 32767 → 10 V (KL4004)

Calibrate so $ANOUT[1]=1.0 → 10 V = max extrude rate. Bench-test before any print.

#### Power

Licensed electrician. 480V 3-phase to the KR C2, sized to its nameplate (7.3 kVA standard / 13.5 kVA heavy-duty — not the sum of axis drive ratings). The heated bed/chamber, extruder control box, dryer, and autoloader each go on their own circuits.

Confirm the extruder control box accepts an external RUN + speed input before ordering the I/O island.

Software

## From model to robot motion

1

##### CAD → Cura

Slice the STL in Ultimaker Cura with the CuraToKRC2 plugin.

2

##### Configure

krl_config.json: tool A/B/C, HOME, Tool & Base numbers, flow constant. Enable Relative Extrusion.

3

##### Export KRL

Native .src/.dat, auto-split into subroutines to fit KR C2 RAM.

4

##### Transfer

Copy files to the controller via USB or network share.

5

##### Run

Robot follows the path; writes $ANOUT[1] for flow, toggles $OUT[n] for extrude on/off.

### Four toolchains — and which to use

From CAD/STL to robot motion. For a KR C2 (KSS 5.x) the pragmatic path is offline KRL — generate, simulate, transfer. Don't stream for production printing.

Path | Control model | Multi-axis | Cost | KR C2 fit
CuraToKRC2 | Static KRL, $ANOUT[1] flow | No (planar) | Free | Purpose-built; RAM-chunked
KUKA|prc | Parametric, full simulation | Yes (6-axis) | Free / €450 | Supported; LFAM precedent
RoboDK | Offline KRC2 post (3D-print mods built in) | Good | $3,995 | KRC2 / KRC2_DAT posts
ROS RSI | Streamed joint correction (12 ms) | Yes | Free | Confirmed on KSS 5.x — research-grade

#### Recommended path

Start free with CuraToKRC2 to commission the $ANOUT[1] flow mapping and DeviceNet I/O on flat prints, move to RoboDK Professional (stock KUKA KRC2 post) for production, and reach for KUKA|prc only if you need non-planar / multi-axis. Avoid real-time streaming for production.

Digital twin: open the ROS-Industrial kuka_kr150_support meshes (or the RoboDK KR 150 R3100-2 model) to verify reach, collisions, and the BASE/TOOL frames before touching the arm. → Full software & simulation assessment in the Build Manual

Calibration

## Tie the model, the nozzle, and the table together

Calibration process diagram: Tool TCP 4-point, Base 3-point, and nozzle-to-build-surface Z-offset verification with acceptable gap of 0.05 to 0.15 mm

Calibration process. Tool TCP (4-point), Base (3-point), and nozzle-to-surface Z-offset verification — with point layouts and best practices. Click to enlarge

#### Tool (TCP) — XYZ 4-point

Setup ▸ Measure ▸ Tool ▸ XYZ 4-point

Touch the nozzle tip to one fixed point from 4 orientations; the controller computes the TCP. Enter the tool A/B/C to match krl_config.json. Save as the Tool number.

#### Base — 3-point

Setup ▸ Measure ▸ Base ▸ 3-point

With the taught TCP, touch the table's 3 reference features: origin, a point on +X, a point in the XY plane. This builds the print coordinate frame. Save as the Base number.

#### Verify

Jog to Base 0,0,0 — the nozzle should sit at the table origin; +X and +Y run along the table edges. Re-touch the references after any crash.

Roadmap

## Commissioning sequence

Indicative effort per phase. Gate everything on step 2 — do not run the arm near the table until the door interlock and every E-stop are proven to stop it.

Commissioning roadmap: seven stages — electrical, safety, I/O integration, software, calibration, test print, production — each with status (complete, in progress, pending, not started)

Commissioning roadmap. Seven stages from power-up to production, with current status at each gate. Click to enlarge

Bill of Materials

## Interactive parts & budget

Filter by status, search, or sort any column. The total updates to the rows currently shown.

All Have Buy Verify Optional Skip

Subsystem | Item | Spec / Model | Status | Cost (USD) | Notes

ROWS SHOWN

SUM OF SHOWN ROWS

REMAINING TO BUY (ENTRY PATH)

Who Does What

## Three owners, one cell

#### Licensed Electrician

480V feeder, disconnect, grounding, and the high-power bed/chamber circuits.

#### Safety Integrator

X11 / ESC wiring of fence interlock + E-stops, and validation that they stop the robot.

#### You

Table, bed, enclosure shell, I/O island, slicer setup, and calibration — stage and bench-test.

Resolve first: confirm the extruder control box accepts an external RUN/STOP + speed signal. That single answer decides how good the prints can be — check its wiring manual before ordering the I/O island.

In Operation

## The finished cell

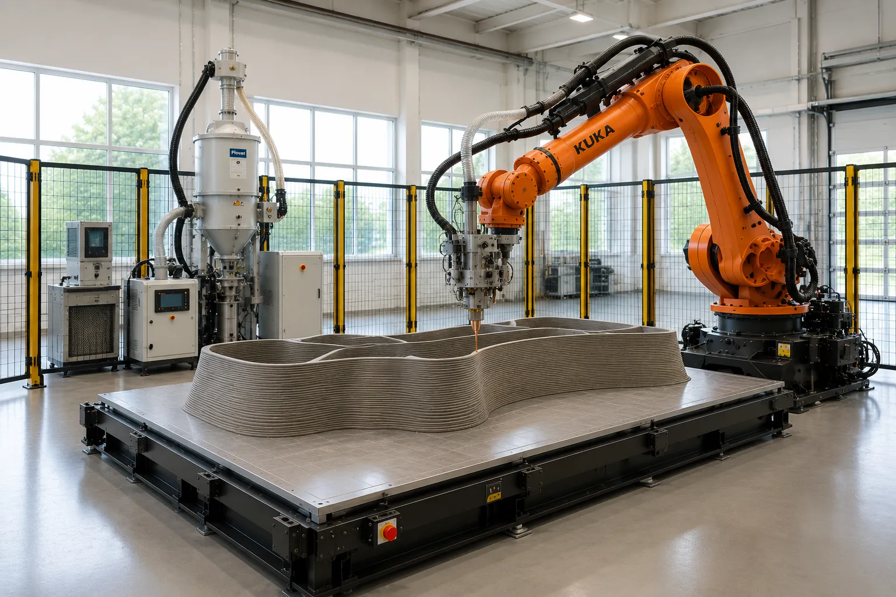
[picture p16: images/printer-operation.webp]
The completed KUKA pellet printer cell with a large printed part on the heated build platform, dryer and control cabinet alongside


Cell in operation. The integrated KUKA pellet printer mid-build — arm, heated platform, and feed chain working as one system. Click to enlarge

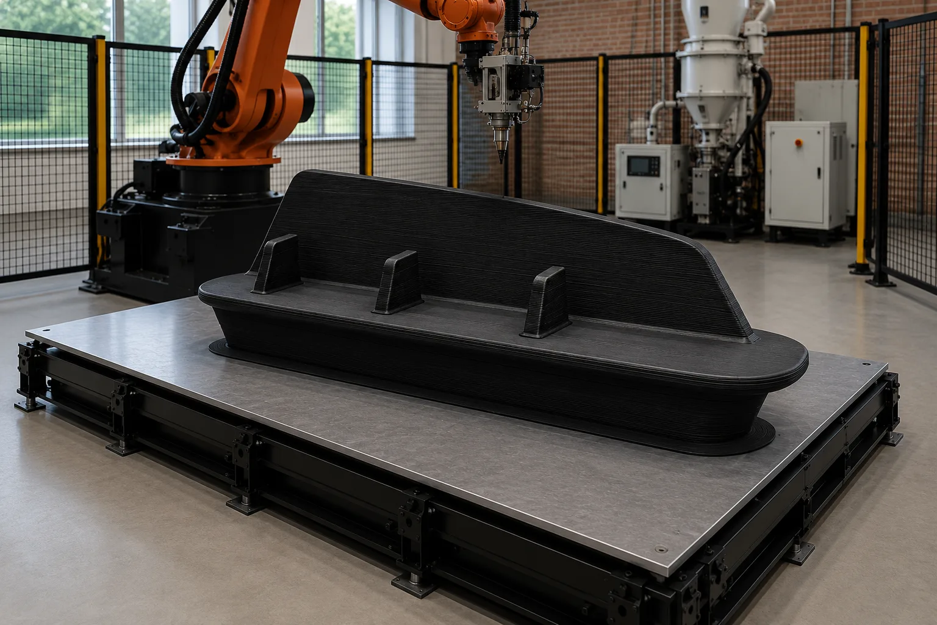
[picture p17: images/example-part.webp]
A large black pellet-printed component with visible bead layer lines, as-printed on the heated build platform of the KUKA cell


Example printed product. A large engineering-thermoplastic part straight off the platform — visible LFAM bead lines, no filament. Click to enlarge

#### Sources

- KR C2 X11 / ESC safety-circuit pin scheme (https://industrialmonitordirect.com/blogs/knowledgebase/kr-c2-ed2005-x11x12-safety-circuit-jumper-configuration-for-standalone)
- KR C2 DeviceNet I/O config (iosys.ini, $ANOUT / $OUT) (https://industrialmonitordirect.com/blogs/knowledgebase/kuka-krc2-devicenet-beckhoff-kl4004-analog-output-configuration)
- CuraToKRC2 plugin (krl_config.json, $ANOUT flow, RAM chunking) (https://www.robot-forum.com/robotforum/thread/55449-open-source-cura-to-kuka-krl-src-plugin-for-krc2-3d-printing-additive-manufactur/)
- KR 150/180/210 technical data (payload, reach, ISO 9409 flange) (https://www.robot-store.co.uk/wp-content/uploads/2021/07/KR210-Robot-Manual.pdf)
- KUKA Tool (XYZ 4-point) & Base (3-point) calibration (https://www.robot-forum.com/robotforum/thread/37320-base-calibration/)
- RoboDK robot 3D printing (RSI streaming alternative) (https://robodk.com/doc/en/Robot-Machining-Robot-3D-Printing-Project.html)

Prepared June 2026 · For planning use. Power and safety-circuit work must be performed by qualified, licensed professionals.

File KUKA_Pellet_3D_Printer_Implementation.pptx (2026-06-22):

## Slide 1

INDUSTRIAL ADDITIVE MANUFACTURING

Converting a KUKA Robot
into a Pellet 3D Printer

Implementation Plan — Platform, Wiring & Software

KR 150 / 180

KR C2 Controller

Pellet Extrusion (LFAM)

June 2026

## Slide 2

THE GOAL

A robotic large-format pellet printer

A 6-axis KUKA arm carries a pellet extruder and prints large parts directly from plastic granules — no filament. The heavy-payload arm, the extruder, and the full feedstock chain are in hand; the work ahead is integration, a build platform, and safety.

Pellets in. Big parts out.

150–180 kg

Robot payload — carries any pellet head with margin

~2700 mm

Reach — defines the build envelope & cell size

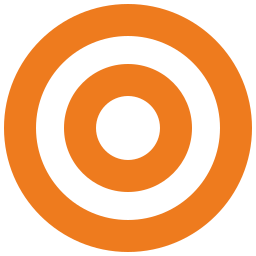
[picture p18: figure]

3–4 kg/h

Extruder output — moderate LFAM throughput

0–350 °C

Melt range — covers PP, PETG, ABS, PA, PC

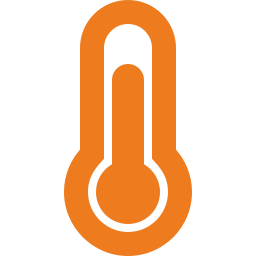
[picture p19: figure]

KUKA · LFAM

2

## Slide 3

WHAT'S IN HAND

Current assets

Robot + Controller

KUKA KR 150 / 180
KR C2 (MP9), KCP2 pendant
480V 3-phase

Pellet Extruder

4 kg/h vertical servo
1200 W · 0–350 °C
1.5–3 mm nozzle

Hopper Dryer

INTSUPERMAI 110 lb
Dries hygroscopic resins
(ABS, PC, PA, PET)

Vacuum Autoloader

INTBUYING XC-300G
300 kg/h · 7.5 L
Feeds the extruder hopper

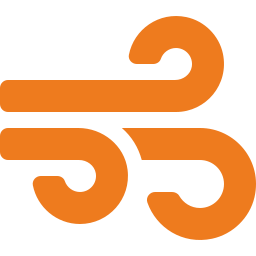
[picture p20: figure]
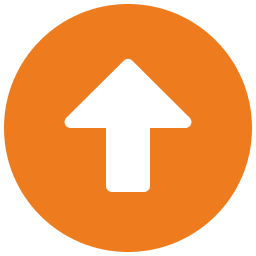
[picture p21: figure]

HAVE

HAVE

HAVE

HAVE

KUKA · LFAM

3

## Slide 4

WHERE YOU STAND

The four subsystems

A

Motion

HAVE

Robot arm + KR C2 controller

B

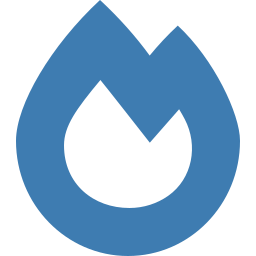
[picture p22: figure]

Extrusion

HAVE

Pellet extruder, heat zones, nozzle

C

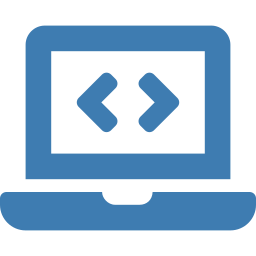
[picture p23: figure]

Control

Slicer → robot toolpath + extruder sync

TO BUILD

D

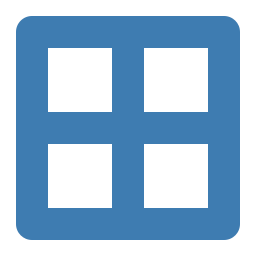
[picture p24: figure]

Platform

Dryer + feed (done); bed, table, enclosure

PARTIAL

KUKA · LFAM

4

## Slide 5

SYSTEM ARCHITECTURE

What connects to what

CAD Model

STL part to print

Slicer PC

Cura + CuraToKRC2 plugin
→ .src / .dat files

KR C2 Controller

Runs KRL motion program

DeviceNet I/O

BK5120 island

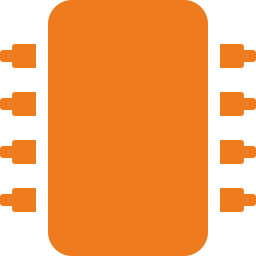
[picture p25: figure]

Robot Arm

carries the head
follows the toolpath

Extruder Control Box

$OUT → RUN/STOP
$ANOUT[1] → speed (0–10V)
$IN ← ready / fault

SELF-REGULATING LOOPS

Barrel heat · bed PID · chamber · dryer — run on their own, not by the robot.

Dryer

dries pellets

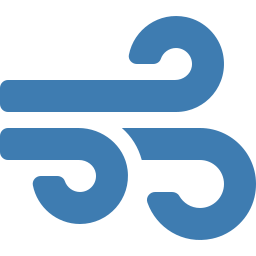
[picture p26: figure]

Autoloader

vacuum-feeds hopper

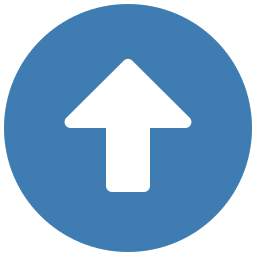
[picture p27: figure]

Heated Build Bed

part adheres here

Amber = robot-controlled in sync with motion Steel = mechanical / feed path

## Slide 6

THE CORE IDEA

The robot does only three things to the extruder

RUN / STOP

Digital output $OUT[n]

Extrude on print moves, stop on travel moves.

SET SPEED

Analog output $ANOUT[1]

0–10 V proportional to sliced flow rate.

READ FAULT

Digital input $IN[n]

Pause the print on an extruder fault.

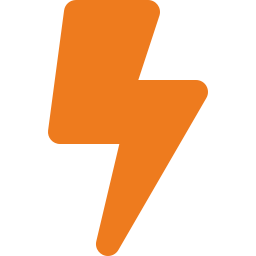
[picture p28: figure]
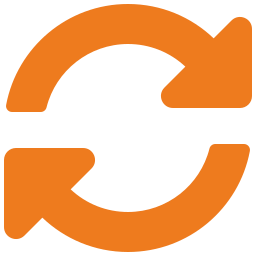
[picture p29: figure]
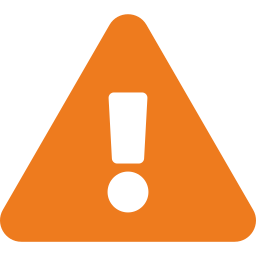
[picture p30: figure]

Everything thermal regulates itself.

Barrel heat zones, the heated bed, the chamber, and the dryer each run on their own controllers. The robot never manages temperature — which keeps the integration small and robust.

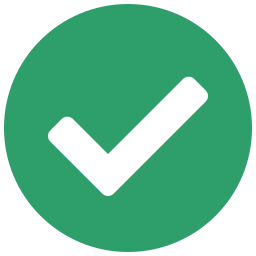
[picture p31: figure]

KUKA · LFAM

6

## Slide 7

PLATFORM · 1 OF 3

Rigid print table, tied to the robot's base frame

Size the build area to the reach — keep it ~1.0–1.5 m square, set 0.7–1.5 m in front of the base.

Build a stiff steel weldment with a thick flat top plate (≥15–20 mm) — it must not flex when the heavy arm decelerates.

Anchor it to the floor, ideally the same slab as the robot, so they can't move relative to each other.

Add 3 hard reference features (dowels / machined pockets) at known XY — these become the base-calibration points.

Mount the heated bed on top, on a thermal break so the frame doesn't sink the heat.

1

BASE FRAME ON THE TABLE

Origin + 2 points teach the print coordinate system. Slice Z=0 then equals the real table top.

Z

2

3

X

4

5

KUKA · LFAM

7

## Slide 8

PLATFORM · 2 OF 3

Heated build bed — adhesion & warp control

Build surface: flat aluminum tooling plate or borosilicate glass, sized to the build area.

Heat with a high-wattage 240V silicone pad bonded underneath (LFAM beds run ~1.5 kW to 5 kW+).

Control as an independent loop — thermocouple → PID controller → SSR → heater.

Mount on the table over insulation + thermal-break standoffs to protect it and save energy.

Adhesion: PEI sheet or glue, plus a wide brim/raft in the slice for big beads.

1

INDEPENDENT CONTROL LOOP

Thermocouple

PID Controller

Solid-State Relay

Silicone Heater

Runs by itself — the robot never sets bed temperature.

2

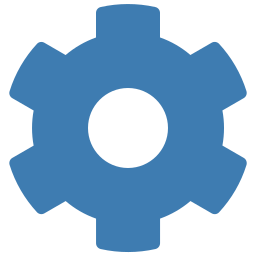
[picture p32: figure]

3

4

5

KUKA · LFAM

8

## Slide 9

PLATFORM · 3 OF 3

Enclosure, fencing & safety interlocks

Machine guarding (required)

Fence beyond the swept volume, one interlocked door, E-stops inside and out. A KR 150/180 at speed is lethal.

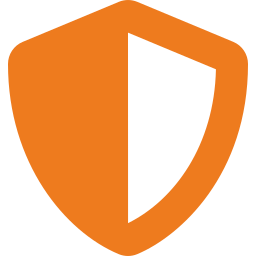
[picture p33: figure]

Thermal & fume chamber

Insulated/poly panels keep a warm chamber (~60 °C, up to 150 °C) and contain fumes — duct an extractor out.

WIRED INTO THE KR C2 SAFETY CIRCUIT (X11 / ESC — dual channel)

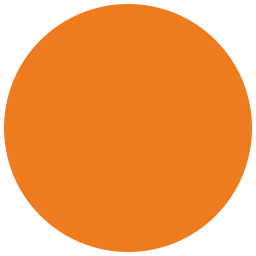
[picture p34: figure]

Door interlock → Operator Safety C8–C10 / C9–C11

External E-stops → C14–C15 / C16–D1

Replace bridges with devices — never leave jumpered

Safety-circuit wiring must be done and validated by a qualified machine-safety integrator — not improvised with permanent jumpers.

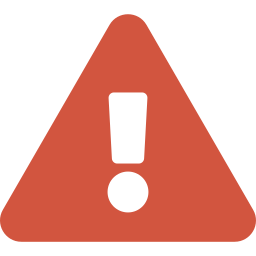
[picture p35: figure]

KUKA · LFAM

9

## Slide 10

ELECTRICAL & I/O

The DeviceNet I/O island

KR C2

DeviceNet master

BK5120

DeviceNet coupler
MACID 11

KL4004 — Analog Out

$ANOUT[1] → extruder speed (0–10 V)

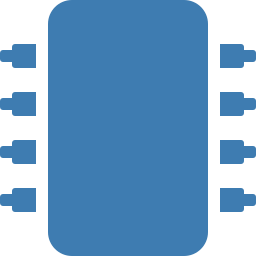
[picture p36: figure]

KL2xxx — Digital Out

$OUT[n] → extruder RUN / heater enable

MAPPED IN iosys.ini

ANOUT1=11,0,16,3
outb0=11,8,x3
Full-scale 0x6C00 = 27648 → 10 V

Calibrate so $ANOUT[1]=1.0 → 10 V = max extrude rate. Bench-test before any print.

KL1xxx — Digital In

$IN[n] ← extruder ready / fault

Power (licensed electrician): 480V 3-phase to the KR C2 sized to its nameplate (~7.5–13 kVA, not the sum of drive ratings). Bed, extruder box, dryer & loader on their own circuits.

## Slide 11

SOFTWARE

From model to robot motion

CAD → Cura

Slice the STL in Ultimaker Cura with the CuraToKRC2 plugin.

1

Configure

krl_config.json: tool A/B/C, HOME, Tool & Base numbers, flow constant. Enable Relative Extrusion.

2

Export KRL

Generates native .src / .dat, auto-split into subroutines to fit KR C2 RAM.

3

Transfer

Copy files to the controller via USB or network share.

4

Run

Robot follows the path; writes $ANOUT[1] for flow, toggles $OUT[n] for extrude on/off.

5

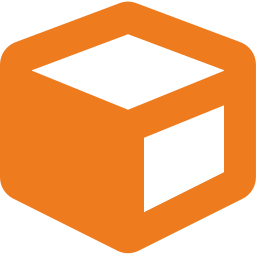
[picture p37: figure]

Upgrade paths: KUKA|prc (Rhino/Grasshopper) for simulation & non-planar toolpaths · RoboDK + KUKA.RSI for live streaming (~4–12 ms) — add later, no drive changes.

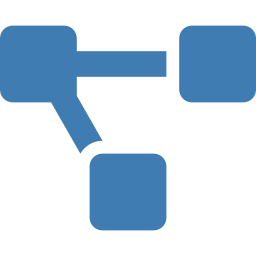
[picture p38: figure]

KUKA · LFAM

11

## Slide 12

CALIBRATION

Tie the model, the nozzle, and the table together

Tool (TCP) — XYZ 4-point

Setup ▸ Measure ▸ Tool ▸ XYZ 4-point
Touch the nozzle tip to one fixed point from 4 orientations; the controller computes the TCP. Enter the tool A/B/C to match krl_config.json. Save as the Tool number.

Base — 3-point

Setup ▸ Measure ▸ Base ▸ 3-point
With the taught TCP, touch the table's 3 reference features: origin, a point on +X, a point in the XY plane. This builds the print coordinate frame. Save as the Base number.

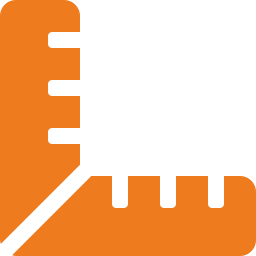
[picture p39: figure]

Verify: jog to Base 0,0,0 — the nozzle should sit at the table origin; +X and +Y run along the table edges. Re-touch after any crash.

KUKA · LFAM

12

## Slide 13

ROADMAP

Commissioning sequence

Gate everything on Step 2

Do not run the arm near the table until the door interlock and every E-stop are proven to stop it.

First real print: a single-wall cylinder in PP or PETG (no drying needed) to dial in temp, bead width & flow.

KUKA · LFAM

13

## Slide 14

BUDGET

Remaining spend — entry path

~$12.8k

estimated remaining for a working entry-level cell

Already owned

Robot, extruder, dryer & autoloader. Skipping the EtherCAT/drive swap avoids several thousand more.

KUKA · LFAM

14

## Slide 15

WHO DOES WHAT

Three owners, one cell

Licensed Electrician

480V feeder, disconnect, grounding, and the high-power bed/chamber circuits.

Safety Integrator

X11 / ESC wiring of fence interlock + E-stops, and validation that they stop the robot.

You

Table, bed, enclosure shell, I/O island, slicer setup, and calibration — stage and bench-test.

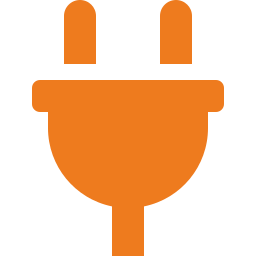
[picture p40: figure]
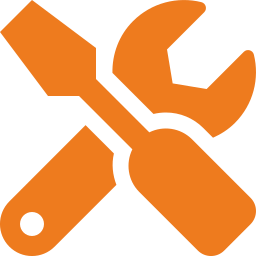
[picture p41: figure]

Resolve first: confirm the extruder control box accepts an external RUN/STOP + speed signal. That single answer decides how good the prints can be — check its wiring manual before ordering the I/O island.

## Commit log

2026-06-22 KUKA pellet 3D printer conversion plan
2026-06-22 Redesign: refined light technical spec-sheet aesthetic
    Modern grotesk + mono typography (Space Grotesk / Inter / IBM Plex Mono),
    blueprint-grid hero, hairline-bordered surfaces with hover lift, restrained
    steel + KUKA-orange accents, light schematic diagram, and light-tuned charts.
    Content, structure, and interactivity unchanged.
2026-06-23 Polish: SVG line icons, hero robot-arm illustration, motion
    Replace all emoji with inline Lucide-style stroke icons; add a hand-built
    robotic-arm + extruder line illustration in the hero; thin scroll-progress
    indicator; IntersectionObserver scroll-reveal with staggered fade-up and
    animated status bars. Respects prefers-reduced-motion; progressive enhancement.
2026-06-23 Add system imagery: showcase photo, 4 technical diagrams, click-to-zoom
    - 6 WebP images (~1.4MB total, optimized from ~13MB PNG)
    - Showcase photo band after hero; closing in-operation photo before footer
    - Material-flow diagram in Assets; exploded view in Architecture;
    build-platform drawing in Platform; calibration diagram in Calibration
    - Reusable figure component (theme-aware frame, caption) + lightbox
    (click to enlarge, click/Esc to close)
    - Lazy-loaded with width/height to avoid layout shift; new bands are
    <div> not <section> so zebra striping is preserved
2026-06-23 Add roadmap + applications imagery, link-preview card, default light mode
    - Commissioning-roadmap diagram in Roadmap section (below effort chart)
    - New 'What you can build' Applications band + nav link (applications grid)
    - Open Graph + Twitter Card meta with dedicated 1200x630 JPEG cover
    (og-cover.jpg) so shared links show a preview image
    - Theme default is now light; dark applies only on explicit saved choice
    (no longer auto-switches to OS prefers-color-scheme)
    - Used only the richer commissioning roadmap (dropped the near-duplicate)
2026-06-23 Add full build manual (guide.html + PDF), research-grade content, brand, software/sim assessment
    Research (5 parallel agents, primary sources) → integrated deliverables:
    - guide.html: 15-section branded engineering build manual — system/specs,
    mechanical & ISO 9409-1-A160 flange, foundation & table, heated bed/thermal,
    enclosure/fume/safety (ISO 10218-2), electrical, DeviceNet I/O & X11 ESC,
    extruder integration, software & simulation, 3D models/digital twin,
    calibration, commissioning, materials reference, BOM, cited sources.
    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
2026-06-23 Add interactive 3D twin (twin.html) + vendored KR 150 model
    - Vendored ROS-Industrial kuka_kr150_support (kr150_2): URDF/xacro + visual
    .dae + collision .stl meshes, Apache-2.0, into model/ with attribution README.
    - twin.html: browser 3D twin (three.js) — assembles the six-axis kinematic
    chain from the package URDF (exact joint origins/axes/limits), jog sliders
    A1-A6, live forward-kinematics tool-tip (TCP) + radial-reach readout, build
    table + print-envelope box + 3.1 m reach circle, Home/Print presets.
    Verified: FK correct (A1=45deg → TCP 1275,-1275,1055 mm), no console errors.
    - Linked from index nav, the Build Manual CTA band, and guide section 10.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
    [base_link.stl, kr150_2.xacro, kr150_2_macro.xacro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]
2026-06-23 Twin: add Collision/Visual mesh-mode toggle
    - Segmented control switches between fast collision STLs (default) and the
    detailed orange visual DAE meshes (ColladaLoader, lazy-loaded on first switch).
    - Per-link holders carry both mesh sets; the shared kinematic chain means
    jogging and the live TCP/FK readout work identically in either mode.
    - Z_UP DAE renders correctly with no rotation (VISUAL_FIX=0); verified toggle
    both ways + jog + Home reset.
2026-06-23 Twin: nozzle/TCP, reach warning, drag-IK, and upload→slice→print preview
    Three interaction modes (Jog / Drag IK / Print) in the KR 150 twin:
    - Extruder + nozzle mounted at the flange; TCP reported at the nozzle tip.
    - Reach/limit status pill turns red when the TCP leaves the 3.1 m envelope.
    - Drag IK: TransformControls gizmo + CCD solver (joint-limit clamped) drives
    the tip to a dragged target — verified ~1 mm accuracy, out-of-reach detected.
    - Print: upload an STL (file picker or drag-drop) or load the bundled sample;
    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
    [vase.stl]
2026-06-23 Twin: orientation-constrained (vertical) IK + default visual mesh
    - Nozzle stays vertical (points straight down) during IK and print-follow.
    The KR 150 wrist is spherical (A4/A5/A6 intersect at the link_5 origin =
    wrist centre, set by A1-A3 only), so the solver is decoupled: arm drives the
    wrist centre to target+WC_TO_TIP·up, wrist orients the tool to -Z. Verified
    0° tilt with 1-2 mm position error across the build area.
    - 'Keep nozzle vertical' toggle in Drag IK (default on); print follow-arm forces
    vertical. Live nozzle-tilt readout (° from vertical) added.
    - Default mesh mode is now Visual (collision still available via the toggle;
    loader waits for visual when it's the acti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
2026-06-23 Nav: pin 3D Twin + Manual to the right of the top bar (always visible)
    - index nav split into a scrolling section-link group and a fixed right cluster
    (3D Twin, Manual, theme toggle) so the page links never scroll off-screen.
    Verified 3D Twin visible at 760px and 1352px wide.
    - Add 3D Twin to the Build Manual (guide.html) top bar too.
2026-06-23 Twin: configurable work cell + crash-zone detection
    - Adjustable enclosure box (Width X / Depth Y / Height Z sliders) to model a
    real install — shrink it to test tighter spaces. Translucent walls + wireframe
    outline; 'Show walls' toggle.
    - Crash detection: the robot+tool (collision meshes) and the loaded part are
    tested against the cell as an exact axis-aligned bounds check; the breached
    wall(s) highlight red and the Cell status shows COLLISION (else CLEAR).
    Runs on every pose change (jog/IK) and during playback; print auto-pauses on
    a crash. 'Crash detection' toggle. Verified: default CLEAR, shrink→COLLISION
    on the correct wall, restore→CLEAR.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
2026-06-23 Twin: hard-stop at walls + self-collision detection
    - Hard-stop: a jog or IK move that would breach a cell wall is reverted to the
    last wall-clear pose (motion is clamped, not just flagged); the IK gizmo
    sticks at the boundary. 'Hard-stop at walls' toggle. Verified: with the cell
    shrunk, A1 jog is held at the wall when on, passes through + flags when off.
    - Self-collision: non-adjacent link AABBs (collision meshes + tool) tested for
    overlap, shrunk 60 mm to tolerate normal folding; offending links highlighted
    with red Box3 hazard boxes. 'Self-collision' toggle + status. Verified: home
    and print poses CLEAR, a folded pose flags SELF-HIT.
    - Cell panel now shows separate Walls / Sel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
2026-06-23 Twin: enable 'Follow with arm (IK)' by default
2026-06-23 Twin + manual: light/dark themes, per-side work cell, dimension annotations, smoother gcode playback
    Twin:
    - Light/dark theme toggle (shares the site 'kuka-theme' preference); themes both
    the panel UI and the 3D scene (background, ground, grid). Default dark.
    - Work cell is now adjustable per-side: Front/Back/Left/Right/Top distance
    sliders (4 walls + ceiling), replacing the symmetric W/D/H.
    - Engineering dimension annotations (CSS2D, semi-opaque chips): live W/D/H of the
    crash zone on the box edges + a build-plate footprint outline & '1200 × 1200 mm'
    label. Cell walls/wireframe/reach are now high-contrast in light mode (fixes the
    near-invisible cell on a light background).
    - Gcod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
2026-06-23 Twin: import & play external G-code (Cura/PrusaSlicer/etc.)
    Print mode now accepts a .gcode/.gco/.g/.nc file (drop or pick) in addition to
    STL. Parses G0/G1 moves with G90/G91 + M82/M83 + G92 handling; a move is a
    deposit when E increases, else a travel. Builds the same toolpath, auto-fits to
    the build area on the table, and runs it through the existing arc-length
    playback, IK-follow, and crash detection. Verified: 6-layer square (24 deposits,
    6 travels correctly excluded), uniform 15 mm/frame playback, plays + follows.
    Refactored slice/gcode paths through a shared finalizePath().
2026-06-23 Twin: Dimensions toggle + more transparent annotations; index: example printed product
    - Twin: 'Dimensions' checkbox shows/hides the cell + build-plate annotations;
    dimension chips dropped to ~40-50% opacity (themed per light/dark).
    - Index: add example-part.webp (pellet-printed component on the platform) as an
    'Example printed product' figure in the closing band near the bottom.
2026-06-25 twin: model offset pellet extruder head (off-centre TCP)
    Replace the coaxial stub head with a parametric CEAD/MDPE10-class head:
    adapter collar, manifold block, vertical barrel offset off the flange
    centreline, motor/feed section, and an off-centre nozzle. Nozzle axis
    stays flange +X (down); only the TCP moves off-axis.
    - TIP=0.48 (axial standoff) + new TIP_LAT=0.15 (lateral offset); tip at
    (TIP, TIP_LAT, 0)
    - vertical IK now orients flange +X down then CCDs the real offset tip
    onto the target; drop the coaxial WC_TO_TIP scalar
2026-06-25 Add inline SVG favicon to served pages
    Kills the /favicon.ico 404 on the live site. Data-URI (dark tile + steel
    barrel + orange nozzle), so no extra network request and no icon file.
